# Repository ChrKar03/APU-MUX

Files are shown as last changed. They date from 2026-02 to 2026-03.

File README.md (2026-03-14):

# APU-MUX: Multiplexer System for UAV Autopilots

This repository contains the research, source code, and validation steps for a UAV Autopilot Multiplexer System. The project aims to create a redundancy mechanism that switches control between two Autopilot Units (APU) to a single set of actuators, enhancing the safety of Unmanned Aerial Vehicles (UAVs).

## 📖 Project Overview

The core function of this system is to act as a "coordinator" between two redundant autopilots. It operates with zero intelligence regarding flight dynamics, focusing solely on signal integrity and switching reliability.

Key Responsibilities:

    Sample Input: Capture PWM signals from APU #1 and APU #2.

    Reproduce Output: Generate a PWM signal for the actuators based on the selected input.

    Switching Logic: Select which APU controls the drone via a switching mechanism (GPIO trigger).

## 🛠 Hardware Architecture

The research was conducted in two phases using STMicroelectronics development boards.
### Phase 1: STM32G4 (Nucleo-G474RE)

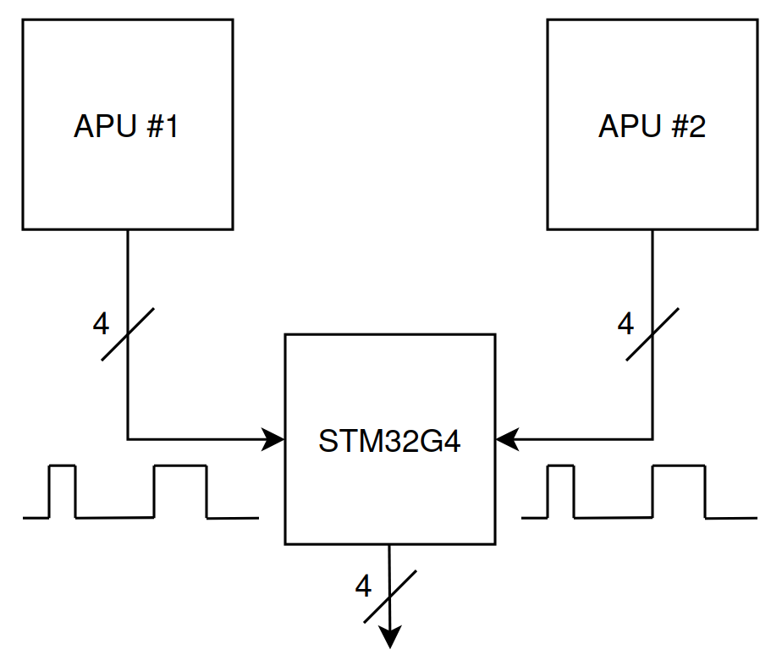
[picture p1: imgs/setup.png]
setup


Used for initial exploration of PWM input sampling and High-Resolution Timer (HRTIM) output.

    Input: 8 Timers (HTIMs) used in PWM Input mode to capture Period and Duty Cycle.

    Output: 4 High-Resolution Timers (HRTIMs).

    Limitation: The HRTIM hardware on the G4 requires a minimum system clock of 100MHz. This results in a minimum output PWM frequency of ~1526Hz, which is incompatible with standard 50Hz ESCs/Servos.

### Phase 2: STM32H7 (Dual Core M7 + M4)

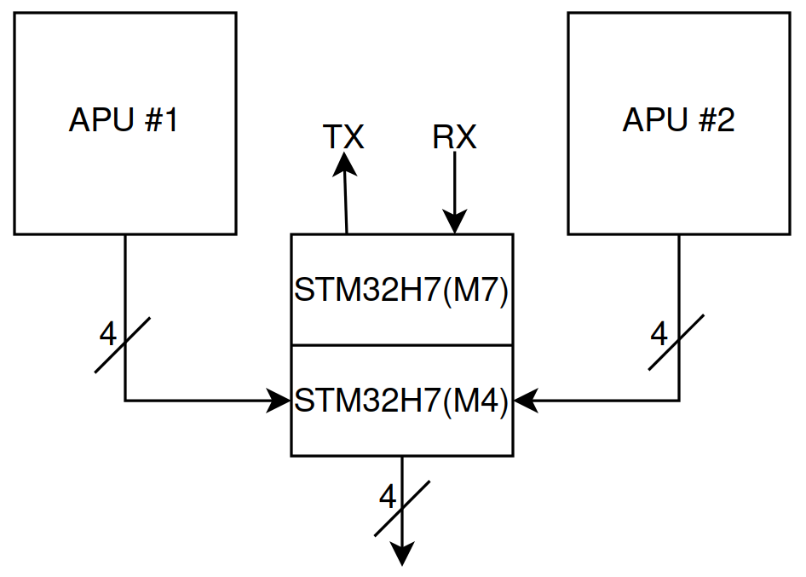
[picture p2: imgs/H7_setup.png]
h7_setup


The final implementation utilizes the STM32H755ZI (Nucleo-144) to overcome frequency limitations and introduce redundancy logic.

    M4 Core: Dedicated to "hard real-time" tasks: PWM sampling and forwarding.

    M7 Core: Handles "intelligent" tasks and serial communication.

    Clock Configuration: System clock set to 80MHz with timer clocks at 2.5MHz to support standard 50Hz PWM output.

## 💻 Software Implementation Strategy

This repository includes code for three distinct implementation approaches:
1. NVIC (Interrupt-Based)

    Mechanism: Uses global interrupts on input timers to capture PWM data.

    Pros: Simple implementation using HAL libraries.

    Cons: High CPU overhead. Performance degrades at high frequencies due to interrupt overload.

2. DMA (Direct Memory Access)

    Mechanism: Offloads CPU by transferring captured data directly from Input Timer registers to Output Timer registers.

    Memory Mapping: Exploits the memory layout of the STM32 peripherals. Since G4 registers have different bit-widths (16-bit reads vs 32-bit writes), the DMA handles the transfer to achieve autonomous updates.

    Performance: Works perfectly up to 30KHz input frequency with minimal CPU intervention.

3. Dual-Core Setup (STM32H7)

    Architecture:

        Shared Memory: Used to pass data between the M7 and M4 cores.

        Synchronization: Hardware Semaphores (HSEM) synchronize boot sequences and resource access.

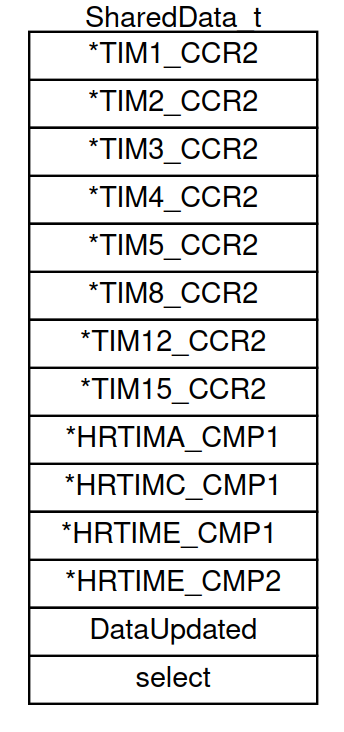
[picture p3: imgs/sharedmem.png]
shared_mem
    

## 🧪 Verification: Hardware-in-the-Loop (HITL)

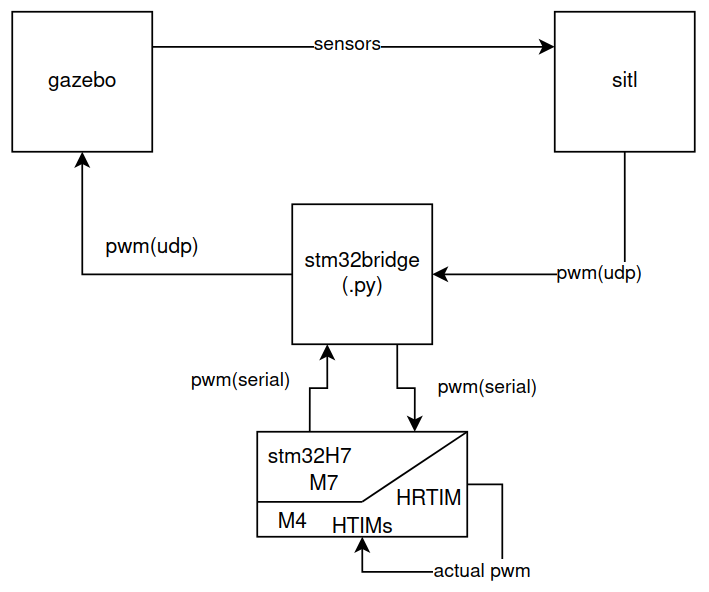
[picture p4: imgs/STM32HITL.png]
hitl


To verify the hardware without risking a physical drone, a HITL environment was created using ArduPilot SITL and Gazebo.

Data Flow:

    Gazebo: Simulates physics and sends sensor data to SITL.

    ArduPilot SITL: Calculates motor outputs and sends them via UDP.

    stm32bridge.py: A Python script that acts as a bridge. It converts UDP packets to Serial data.

    STM32H7: Receives Serial data (M7), generates electrical PWM (M4), samples it back, and returns the read values to the script .

To run the verification experiment, refer to the scripts in the coordinator.py and stm32bridge.py files.
## 🔌 Pinout Configuration

### STM32G474RET
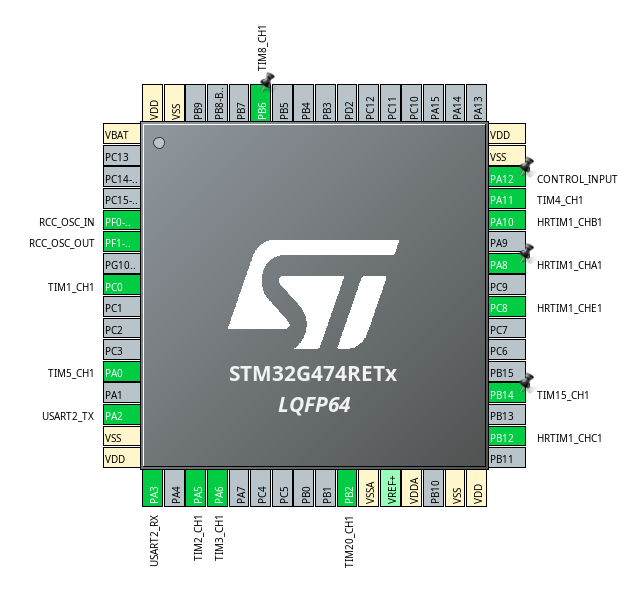
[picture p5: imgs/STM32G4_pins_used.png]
g4_pinout


### STM32H755ZIT
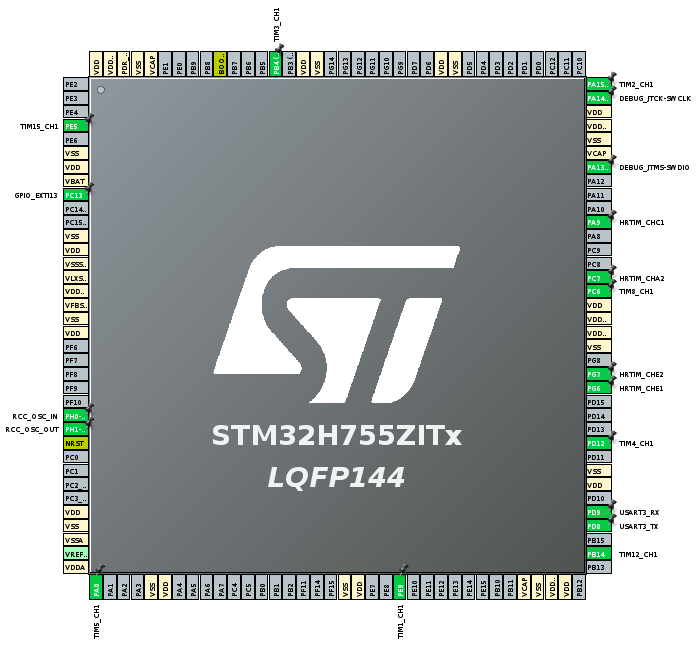
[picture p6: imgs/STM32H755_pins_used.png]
h7_pinout


Note: The system supports 8 inputs mapped to 4 high-resolution outputs.
## 📂 Repository Structure

    imgs/: Images used for this README.

    manuals/: pdf files for the STM32G4's and H7's documentation.

    src/: STM32CubeIDE projects of G4 and H7.

    scripts/: Contains the dma_script.py, nvic_script.py for the G4 and stm32bridge.py for testing H7 and HITL.

    board/: Contains a custom pcb implementation.

## ⚙️ Prerequisites

    IDE: STM32CubeIDE.

    Flash Tool: STM32CubeProgrammer.

    Simulation: ArduPilot SITL, Gazebo 8.10.

    Python Libraries: PyVISA, Serial libraries.

    ArduPilot: https://github.com/ArduPilot/ardupilot.git

    Gazebo 8.10: https://github.com/gazebosim 

    SITL_Gazebo plugin: https://github.com/ArduPilot/ardupilot_gazebo.git

## 📝 Credits

Author: Christos Karagiannis

Institution: University of Thessaly, Department of Electrical and Computer Engineering.

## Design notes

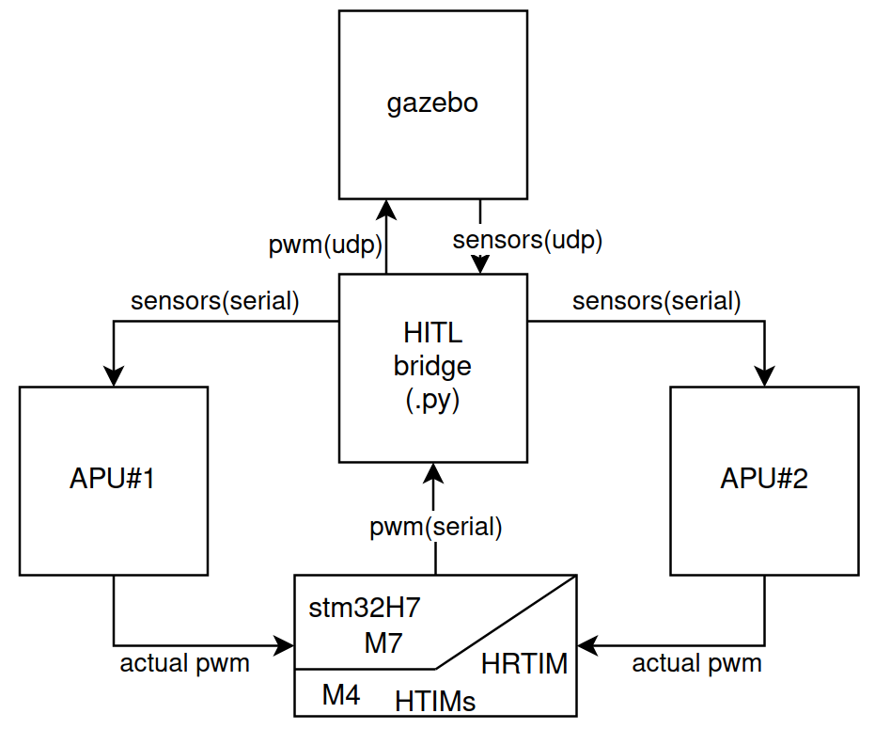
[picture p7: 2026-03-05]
imgs/HITL.png

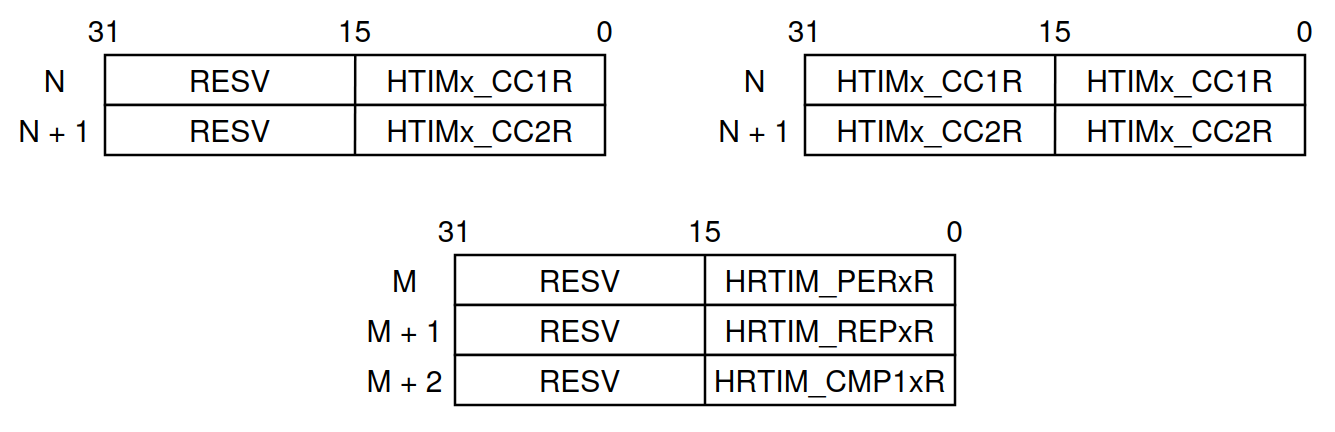
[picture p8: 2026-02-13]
imgs/memory_layout.png

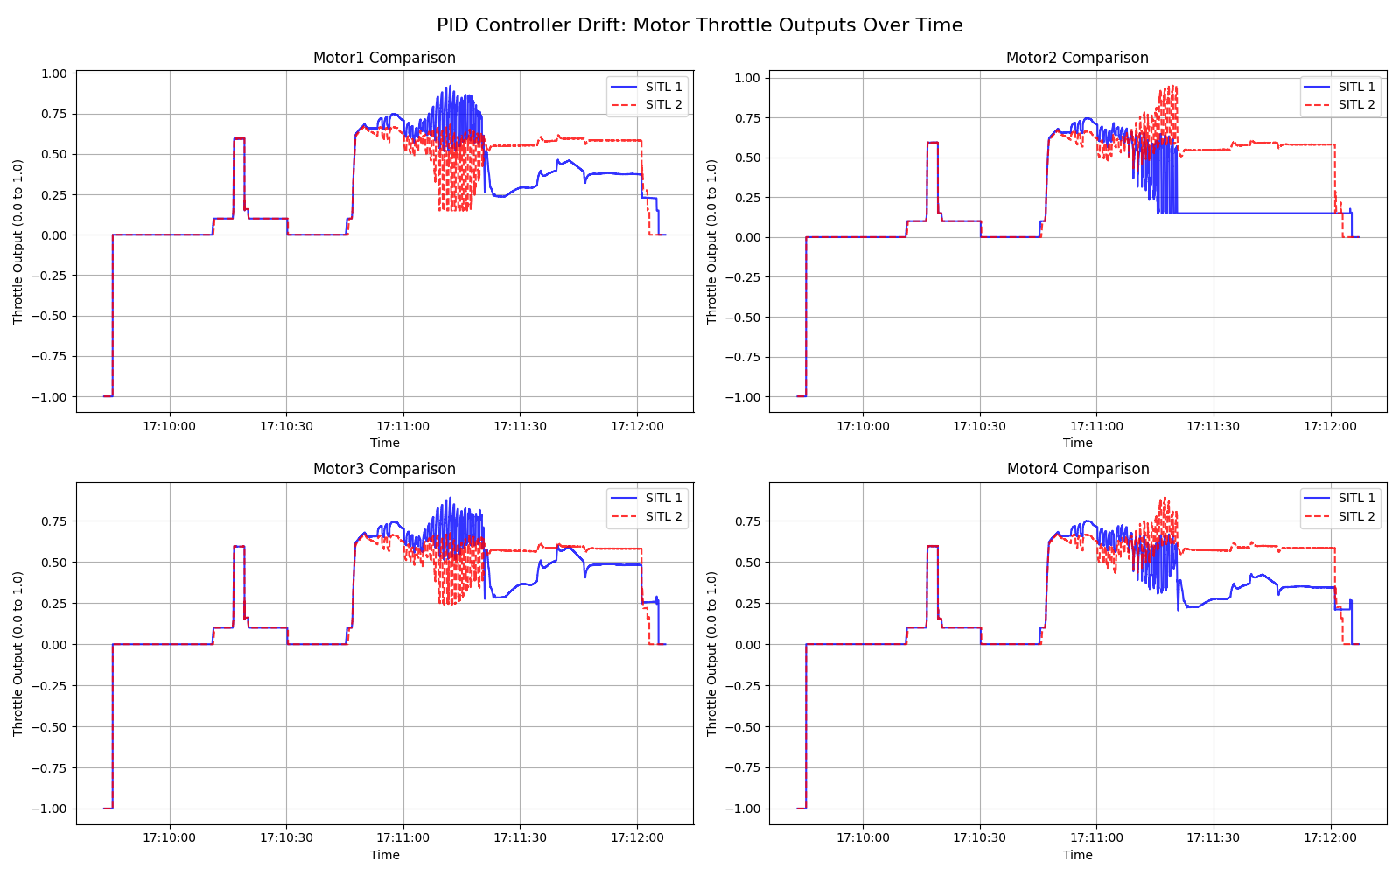
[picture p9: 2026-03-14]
scripts/SWSIM2APU/different/pid_drift_analysis_all_motors_no2.png

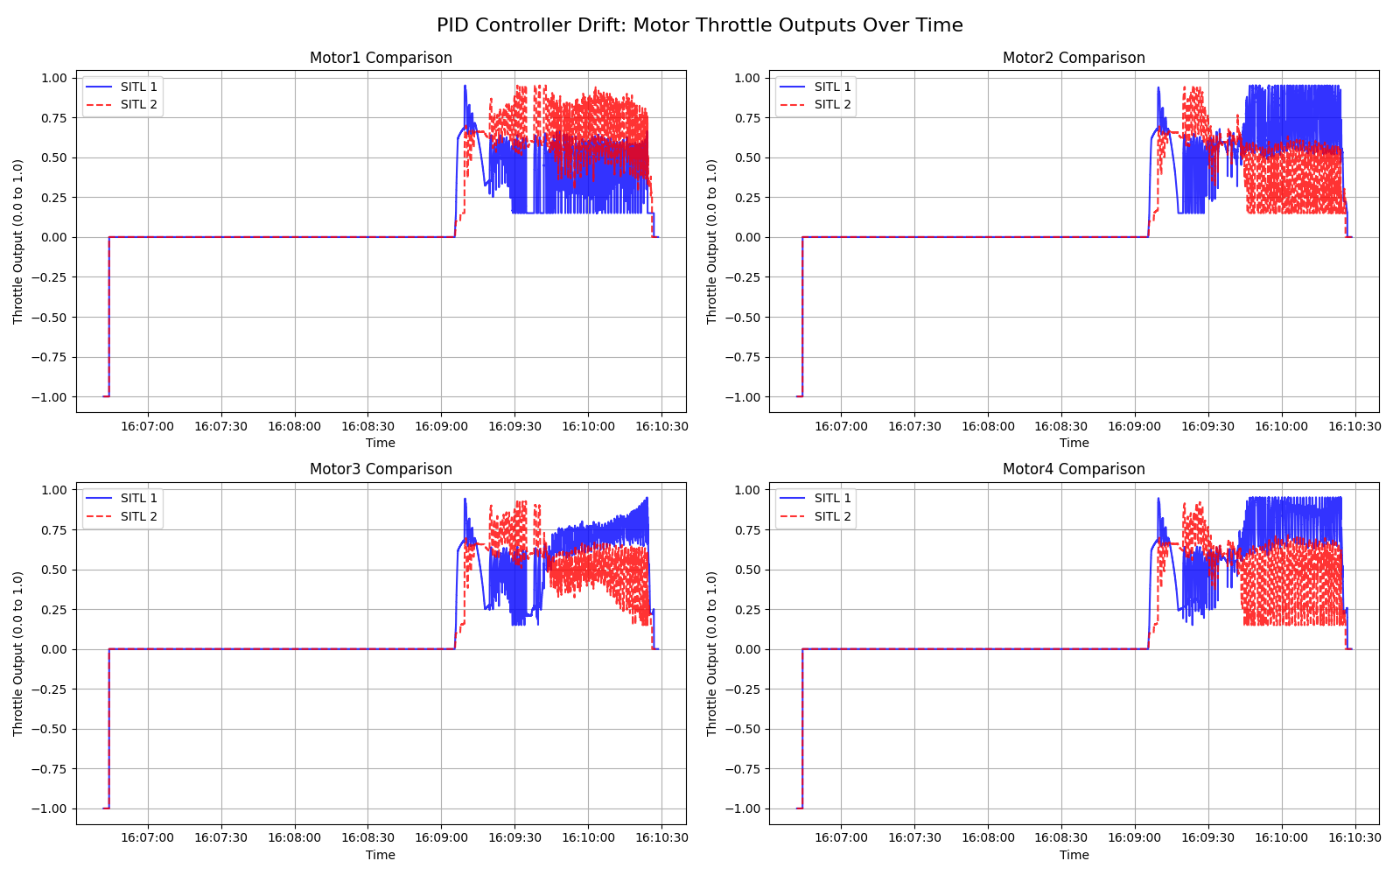
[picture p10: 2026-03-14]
scripts/SWSIM2APU/different/pid_drift_analysis_all_motors_noisy.png

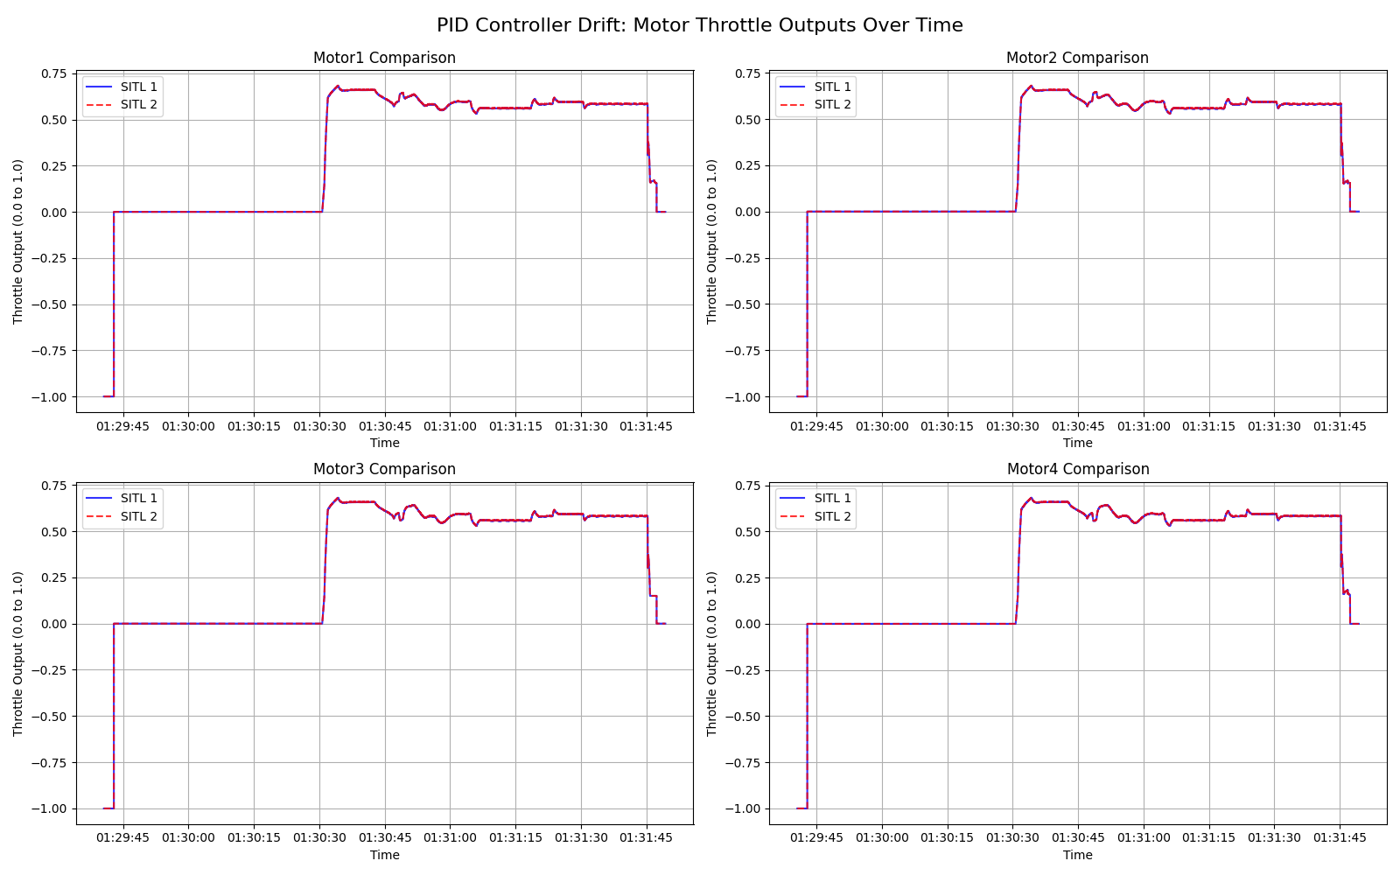
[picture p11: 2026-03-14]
scripts/SWSIM2APU/identical/pid_drift_analysis_all_motors_simple.png

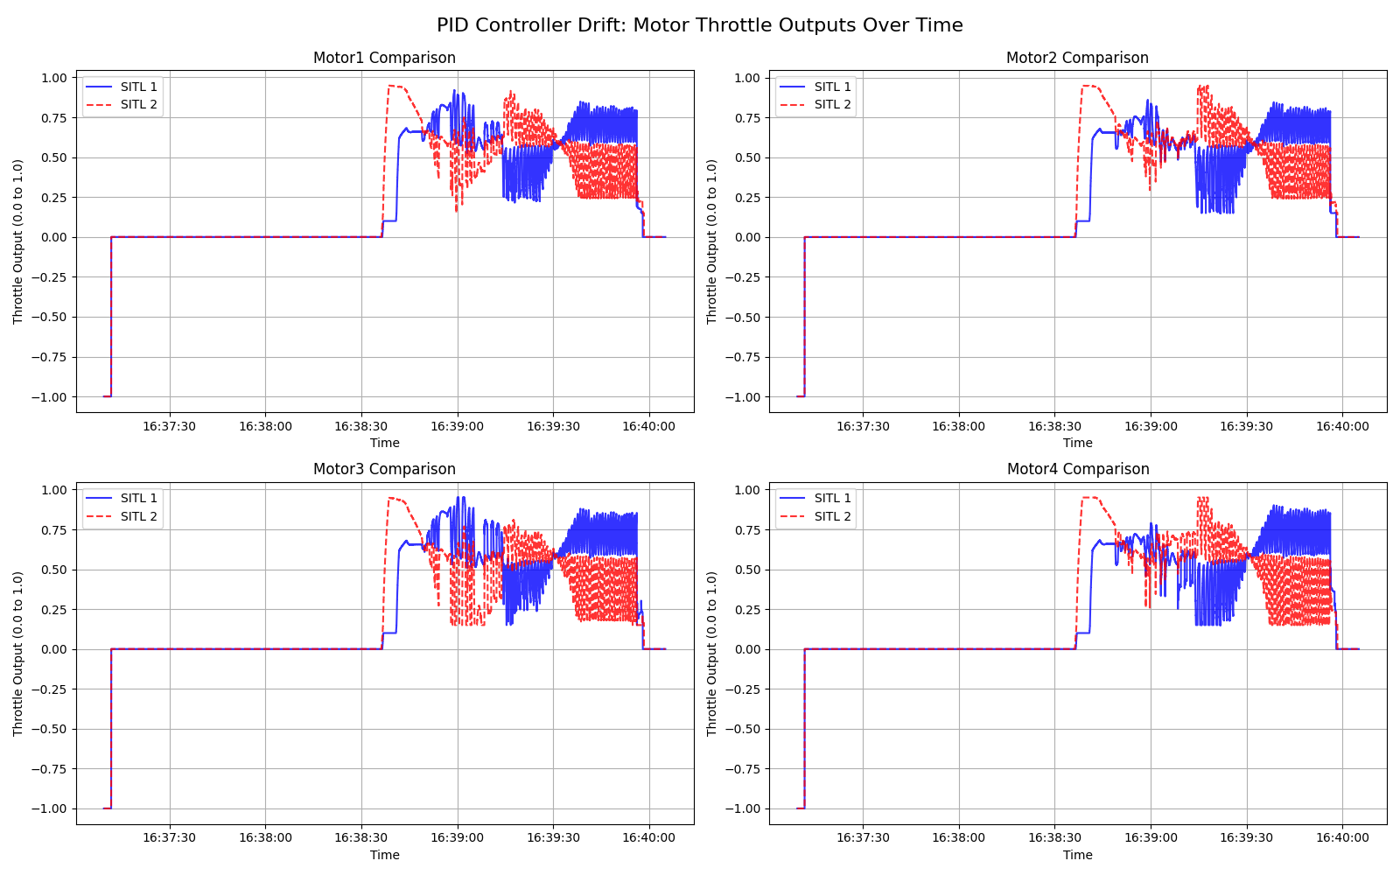
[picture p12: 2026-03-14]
scripts/SWSIM2APU/different/pid_drift_analysis_all_motors_no1.png

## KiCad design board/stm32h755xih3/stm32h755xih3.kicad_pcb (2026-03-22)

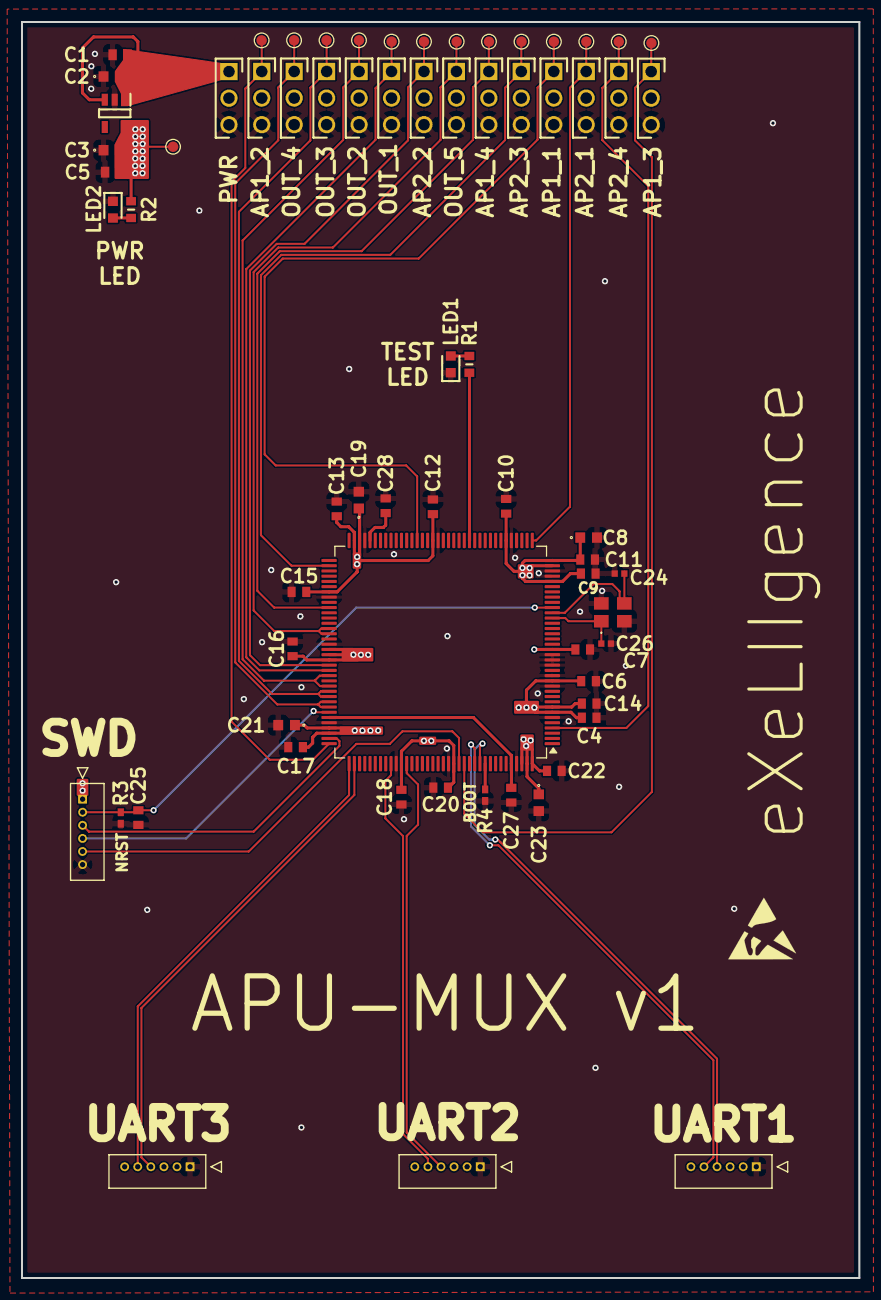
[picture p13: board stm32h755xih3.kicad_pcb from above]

Board: 4 copper layers, 80.0 x 120.0 mm, 55 parts (0 on the bottom side), 34 nets.

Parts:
C1, C5: MLASG168BB5475KTNA01; CAPC1709X100N
C2, C3, C8, C19, C21, C23: C0603X105J4RACTU; C0603
C4, C6, C7, C9, C10, C11, C12, C13, C14, C15, C16, C17, C18, C20, C22, C25: CC0603JRX7R9BB104; CAPC1608X90N
C24, C26: GRM1555C1H8R0DA01D; CAPC1005X70N
C27, C28: 0603YC225MAT2A; CAPC1608X90N
IC1: AP2112K-3.3TRG1; SOT95P285X140-5N
J1, J2, J3, J5, J6, J7, J8, J10, J11, J12, J13, J15, J16, J17: HTSW-101-07-G-T; HDRV3W64P254_3X1_254X756X838P
J4, J9, J14, J18: 53047-0610; 530470610
LED1: LTST-C190KGKT; LEDC1608X80N
LED2: LTST-C190KRKT; LEDC1608X80N
R1, R2: RC0603FR-071KL; RESC1608X55N
R3, R4: RC0402FR-0710KL; RESC1005X40N
U1: STM32H755ZITx; LQFP-144_20x20mm_P0.5mm
Y1: 830059082; LFXTAL085880

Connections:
3V3: C3.2, C4.1, C5.1, C6.1, C7.1, C8.1, C9.1, C10.1, C11.1, C12.1, C13.1, C14.1, C15.1, C16.1, C17.1, C18.1, C19.1, C20.1, C21.1, C22.1, C23.1, IC1.5 (VOUT), J18.1, R2.1, U1.7 (VDD), U1.8 (VBAT), U1.13 (VDD), U1.19 (VDD), U1.32 (VDD), U1.35 (VREF+), U1.36 (VDDA), U1.42 (VDD), U1.56 (VDD), U1.70 (VDDLDO), U1.71 (VDD), U1.79 (VDD), U1.90 (VDD50_USB), U1.91 (VDD33_USB), U1.92 (VDD), U1.105 (VDDLDO), U1.106 (VDD), U1.119 (VDD), U1.129 (VDD), U1.142 (PDR_ON), U1.143 (VDDLDO), U1.144 (VDD)
AP1_1: J1.1, U1.59 (PE9)
AP1_2: J5.1, U1.108 (PA15)
AP1_3: J2.1, U1.131 (PB4)
AP1_4: J6.1, U1.82 (PD12)
AP2_1: J7.1, U1.37 (PA0)
AP2_2: J10.1, U1.93 (PC6)
AP2_3: J8.1, U1.74 (PB14)
AP2_4: J11.1, U1.4 (PE5)
BOOT: R4.1, U1.135 (BOOT0)
GND: C1.2, C2.1, C3.1, C4.2, C5.2, C6.2, C7.2, C8.2, C9.2, C10.2, C11.2, C12.2, C13.2, C14.2, C15.2, C16.2, C17.2, C18.2, C19.2, C20.2, C21.2, C22.2, C23.2, C24.2, C25.2, C26.1, C27.1, C28.1, IC1.2 (GND), J1.3, J2.3, J3.3, J4.1, J5.3, J6.3, J7.3, J8.3, J9.1, J10.3, J11.3, J12.3, J13.3, J14.1, J15.3, J16.3, J17.3, J18.6, LED1.1 (K), LED2.1 (K), R3.2, R4.2, U1.6 (VSS), U1.12 (VSS), U1.14 (VSSSMPS), U1.16 (VDDSMPS), U1.17 (VFBSMPS), U1.18 (VSS), U1.33 (VSS), U1.34 (VSSA), U1.41 (VSS), U1.55 (VSS), U1.69 (VSS), U1.80 (VSS), U1.89 (VSS), U1.104 (VSS), U1.118 (VSS), U1.128 (VSS), U1.141 (VSS), Y1.2 (GND_&_LID_1), Y1.4 (GND_&_LID_2)
NRESET: C25.1, J18.2, R3.1, U1.27 (NRST)
unnamed: C27.2, U1.103 (VCAP), U1.140 (VCAP)
unnamed: C28.2, U1.68 (VCAP)
unnamed: C1.1, C2.2, IC1.1 (VIN), IC1.3 (EN), J3.1
unnamed: LED1.2 (A), R1.2
unnamed: LED2.2 (A), R2.2
OSC1: C26.2, U1.25 (PH0), Y1.1 (CRYSTAL_1)
OSC2: C24.1, U1.26 (PH1), Y1.3 (CRYSTAL_2)
RXD1: J4.4, U1.134 (PB7)
RXD2: J9.4, U1.120 (PD6)
RXD3: J14.4, U1.110 (PC11)
STM32B1/2: J15.1, U1.95 (PC8), U1.97 (PA8)
STM32C1/2: J17.1, U1.98 (PA9), U1.99 (PA10)
STM32D1/2: J13.1, U1.100 (PA11), U1.101 (PA12)
STM32E1/2: J16.1, U1.86 (PG6), U1.87 (PG7)
STM32Α1/2: J12.1, U1.94 (PC7)
SWCLK: J18.3, U1.107 (PA14)
SWDIO: J18.4, U1.102 (PA13)
SWO: J18.5, U1.130 (PB3)
TESTLED: R1.1, U1.49 (PB0)
TXD1: J4.5, U1.133 (PB6)
TXD2: J9.5, U1.117 (PD5)
TXD3: J14.5, U1.109 (PC10)

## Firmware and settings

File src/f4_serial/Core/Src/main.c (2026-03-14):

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
/* Includes ------------------------------------------------------------------*/
#include "main.h"

TIM_HandleTypeDef htim1;
TIM_HandleTypeDef htim2;
TIM_HandleTypeDef htim3;

UART_HandleTypeDef huart2;

/* USER CODE BEGIN PV */

uint16_t pwm_values[8];

/* USER CODE END PV */

void SystemClock_Config(void);
static void MX_GPIO_Init(void);
static void MX_USART2_UART_Init(void);
static void MX_TIM1_Init(void);
static void MX_TIM3_Init(void);
static void MX_TIM2_Init(void);
/* USER CODE BEGIN 0 */

void HAL_UART_RxCpltCallback(UART_HandleTypeDef *huart)
{
	htim1.Instance->CCR1 = pwm_values[0];
	htim1.Instance->CCR2 = pwm_values[1];
	htim1.Instance->CCR3 = pwm_values[2];
	htim2.Instance->CCR1 = pwm_values[3];
	htim3.Instance->CCR1 = pwm_values[4];
	htim3.Instance->CCR2 = pwm_values[5];
	htim3.Instance->CCR3 = pwm_values[6];
	htim3.Instance->CCR4 = pwm_values[7];
	HAL_UART_Receive_IT(&huart2, (uint8_t *)pwm_values, 16);
}

/* USER CODE END 0 */

/**
  * @brief  The application entry point.
  * @retval int
  */
int main(void)
{

  /* MCU Configuration--------------------------------------------------------*/

  /* Reset of all peripherals, Initializes the Flash interface and the Systick. */
  HAL_Init();

  /* Configure the system clock */
  SystemClock_Config();

  /* Initialize all configured peripherals */
  MX_GPIO_Init();
  MX_USART2_UART_Init();
  MX_TIM1_Init();
  MX_TIM3_Init();
  MX_TIM2_Init();
  /* USER CODE BEGIN 2 */
  HAL_UART_Receive_IT(&huart2, (uint8_t *)pwm_values, 16);

  HAL_TIM_PWM_Start(&htim1, TIM_CHANNEL_1);
  HAL_TIM_PWM_Start(&htim1, TIM_CHANNEL_2);
  HAL_TIM_PWM_Start(&htim1, TIM_CHANNEL_3);
  HAL_TIM_PWM_Start(&htim2, TIM_CHANNEL_1);
  HAL_TIM_PWM_Start(&htim3, TIM_CHANNEL_1);
  HAL_TIM_PWM_Start(&htim3, TIM_CHANNEL_2);
  HAL_TIM_PWM_Start(&htim3, TIM_CHANNEL_3);
  HAL_TIM_PWM_Start(&htim3, TIM_CHANNEL_4);
  /* USER CODE END 2 */

  /* Infinite loop */
  /* USER CODE BEGIN WHILE */
  while (1)
  {
    /* USER CODE END WHILE */

    /* USER CODE BEGIN 3 */
  }
  /* USER CODE END 3 */
}

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


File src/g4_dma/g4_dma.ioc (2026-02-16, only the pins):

Mcu.UserName=STM32G474RETx
PA0.Signal=S_TIM5_CH1
PA10.Signal=HRTIM1_CHB1
PA11.Signal=S_TIM4_CH1
PA12.GPIO_Label=CONTROL_INPUT
PA12.Signal=GPXTI12
PA2.Signal=USART2_TX
PA3.Signal=USART2_RX
PA5.Signal=S_TIM2_CH1
PA6.Signal=S_TIM3_CH1
PA8.Signal=HRTIM1_CHA1
PB12.Signal=HRTIM1_CHC1
PB14.Signal=S_TIM15_CH1
PB2.Signal=S_TIM20_CH1
PB6.Signal=S_TIM8_CH1
PC0.Signal=S_TIM1_CH1
PC8.Signal=HRTIM1_CHE1
PF0-OSC_IN.Signal=RCC_OSC_IN
PF1-OSC_OUT.Signal=RCC_OSC_OUT

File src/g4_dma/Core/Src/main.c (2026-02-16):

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
/* Includes ------------------------------------------------------------------*/
#include "main.h"

/* USER CODE BEGIN PD */

#define HRTIMA_PER_ADDR (&HRTIM1->sTimerxRegs[HRTIM_TIMERINDEX_TIMER_A].PERxR)
#define HRTIMA_CMP1_ADDR (&HRTIM1->sTimerxRegs[HRTIM_TIMERINDEX_TIMER_A].CMP1xR)

#define HRTIMB_PER_ADDR (&HRTIM1->sTimerxRegs[HRTIM_TIMERINDEX_TIMER_B].PERxR)
#define HRTIMB_CMP1_ADDR (&HRTIM1->sTimerxRegs[HRTIM_TIMERINDEX_TIMER_B].CMP1xR)

#define HRTIMC_PER_ADDR (&HRTIM1->sTimerxRegs[HRTIM_TIMERINDEX_TIMER_C].PERxR)
#define HRTIMC_CMP1_ADDR (&HRTIM1->sTimerxRegs[HRTIM_TIMERINDEX_TIMER_C].CMP1xR)

#define HRTIME_PER_ADDR (&HRTIM1->sTimerxRegs[HRTIM_TIMERINDEX_TIMER_E].PERxR)
#define HRTIME_CMP1_ADDR (&HRTIM1->sTimerxRegs[HRTIM_TIMERINDEX_TIMER_E].CMP1xR)
/* USER CODE END PD */

HRTIM_HandleTypeDef hhrtim1;

TIM_HandleTypeDef htim1;
TIM_HandleTypeDef htim2;
TIM_HandleTypeDef htim3;
TIM_HandleTypeDef htim4;
TIM_HandleTypeDef htim5;
TIM_HandleTypeDef htim8;
TIM_HandleTypeDef htim15;
TIM_HandleTypeDef htim20;
DMA_HandleTypeDef hdma_tim1_ch1;
DMA_HandleTypeDef hdma_tim2_ch1;
DMA_HandleTypeDef hdma_tim3_ch1;
DMA_HandleTypeDef hdma_tim4_ch1;
DMA_HandleTypeDef hdma_tim5_ch1;
DMA_HandleTypeDef hdma_tim8_ch1;
DMA_HandleTypeDef hdma_tim15_ch1;
DMA_HandleTypeDef hdma_tim20_ch1;

UART_HandleTypeDef huart2;

void SystemClock_Config(void);
static void MX_GPIO_Init(void);
static void MX_DMA_Init(void);
static void MX_TIM1_Init(void);
static void MX_TIM2_Init(void);
static void MX_TIM3_Init(void);
static void MX_TIM4_Init(void);
static void MX_TIM5_Init(void);
static void MX_TIM8_Init(void);
static void MX_TIM15_Init(void);
static void MX_TIM20_Init(void);
static void MX_USART2_UART_Init(void);
static void MX_HRTIM1_Init(void);
/* USER CODE BEGIN 0 */

uint8_t control_var = 0;
void HAL_GPIO_EXTI_Callback(uint16_t GPIO_Pin)
{
	if(GPIO_Pin == CONTROL_INPUT_Pin)
	{
		if (control_var)
		{
			HAL_TIM_IC_Stop_DMA(&htim2, TIM_CHANNEL_1);
			HAL_TIM_IC_Stop(&htim2, TIM_CHANNEL_2);

			HAL_TIM_IC_Stop_DMA(&htim4, TIM_CHANNEL_1);
			HAL_TIM_IC_Stop(&htim4, TIM_CHANNEL_2);

			HAL_TIM_IC_Stop_DMA(&htim8, TIM_CHANNEL_1);
			HAL_TIM_IC_Stop(&htim8, TIM_CHANNEL_2);

			HAL_TIM_IC_Stop_DMA(&htim20, TIM_CHANNEL_1);
			HAL_TIM_IC_Stop(&htim20, TIM_CHANNEL_2);

			HAL_TIM_IC_Start_DMA(&htim1, TIM_CHANNEL_1, &HRTIM1->sTimerxRegs[HRTIM_TIMERINDEX_TIMER_A].PERxR, 3);
			HAL_TIM_IC_Start(&htim1, TIM_CHANNEL_2);

			HAL_TIM_IC_Start_DMA(&htim3, TIM_CHANNEL_1, &HRTIM1->sTimerxRegs[HRTIM_TIMERINDEX_TIMER_B].PERxR, 3);
			HAL_TIM_IC_Start(&htim3, TIM_CHANNEL_2);

			HAL_TIM_IC_Start_DMA(&htim5, TIM_CHANNEL_1, &HRTIM1->sTimerxRegs[HRTIM_TIMERINDEX_TIMER_C].PERxR, 3);
			HAL_TIM_IC_Start(&htim5, TIM_CHANNEL_2);

			HAL_TIM_IC_Start_DMA(&htim15, TIM_CHANNEL_1, &HRTIM1->sTimerxRegs[HRTIM_TIMERINDEX_TIMER_D].PERxR, 3);
			HAL_TIM_IC_Start(&htim15, TIM_CHANNEL_2);
		}
		else
		{
			HAL_TIM_IC_Stop_DMA(&htim1, TIM_CHANNEL_1);
			HAL_TIM_IC_Stop(&htim1, TIM_CHANNEL_2);

			HAL_TIM_IC_Stop_DMA(&htim3, TIM_CHANNEL_1);
			HAL_TIM_IC_Stop(&htim3, TIM_CHANNEL_2);

			HAL_TIM_IC_Stop_DMA(&htim5, TIM_CHANNEL_1);
			HAL_TIM_IC_Stop(&htim5, TIM_CHANNEL_2);

			HAL_TIM_IC_Stop_DMA(&htim15, TIM_CHANNEL_1);
			HAL_TIM_IC_Stop(&htim15, TIM_CHANNEL_2);

			HAL_TIM_IC_Start_DMA(&htim2, TIM_CHANNEL_1, &HRTIM1->sTimerxRegs[HRTIM_TIMERINDEX_TIMER_A].PERxR, 3);
			HAL_TIM_IC_Start(&htim2, TIM_CHANNEL_2);

			HAL_TIM_IC_Start_DMA(&htim4, TIM_CHANNEL_1, &HRTIM1->sTimerxRegs[HRTIM_TIMERINDEX_TIMER_B].PERxR, 3);
			HAL_TIM_IC_Start(&htim4, TIM_CHANNEL_2);

			HAL_TIM_IC_Start_DMA(&htim8, TIM_CHANNEL_1, &HRTIM1->sTimerxRegs[HRTIM_TIMERINDEX_TIMER_C].PERxR, 3);
			HAL_TIM_IC_Start(&htim8, TIM_CHANNEL_2);

			HAL_TIM_IC_Start_DMA(&htim20, TIM_CHANNEL_1, &HRTIM1->sTimerxRegs[HRTIM_TIMERINDEX_TIMER_D].PERxR, 3);
			HAL_TIM_IC_Start(&htim20, TIM_CHANNEL_2);
		}
	}
	control_var ^= 1;
}

/* USER CODE END 0 */

/**
  * @brief  The application entry point.
  * @retval int
  */
int main(void)
{

  /* MCU Configuration--------------------------------------------------------*/

  /* Reset of all peripherals, Initializes the Flash interface and the Systick. */
  HAL_Init();

  /* Configure the system clock */
  SystemClock_Config();

  /* Initialize all configured peripherals */
  MX_GPIO_Init();
  MX_DMA_Init();
  MX_TIM1_Init();
  MX_TIM2_Init();
  MX_TIM3_Init();
  MX_TIM4_Init();
  MX_TIM5_Init();
  MX_TIM8_Init();
  MX_TIM15_Init();
  MX_TIM20_Init();
  MX_USART2_UART_Init();
  MX_HRTIM1_Init();
  /* USER CODE BEGIN 2 */

//	Test 3: Input/Output only using DMA.
	HAL_TIM_IC_Start_DMA(&htim1, TIM_CHANNEL_1, HRTIMA_PER_ADDR, 3);
	HAL_TIM_IC_Start(&htim1, TIM_CHANNEL_2);

	HAL_TIM_IC_Start_DMA(&htim3, TIM_CHANNEL_1, HRTIMB_PER_ADDR, 3);
	HAL_TIM_IC_Start(&htim3, TIM_CHANNEL_2);

	HAL_TIM_IC_Start_DMA(&htim5, TIM_CHANNEL_1, HRTIMC_PER_ADDR, 3);
	HAL_TIM_IC_Start(&htim5, TIM_CHANNEL_2);

	HAL_TIM_IC_Start_DMA(&htim15, TIM_CHANNEL_1, HRTIME_PER_ADDR, 3);
	HAL_TIM_IC_Start(&htim15, TIM_CHANNEL_2);

//	HAL_TIM_IC_Start_DMA(&htim2, TIM_CHANNEL_1, HRTIMA_PER_ADDR, 3);
//	HAL_TIM_IC_Start(&htim2, TIM_CHANNEL_2);
//
//	HAL_TIM_IC_Start_DMA(&htim4, TIM_CHANNEL_1, HRTIMB_PER_ADDR, 3);
//	HAL_TIM_IC_Start(&htim4, TIM_CHANNEL_2);
//
//	HAL_TIM_IC_Start_DMA(&htim8, TIM_CHANNEL_1, HRTIMC_PER_ADDR, 3);
//	HAL_TIM_IC_Start(&htim8, TIM_CHANNEL_2);
//
//	HAL_TIM_IC_Start_DMA(&htim20, TIM_CHANNEL_1, HRTIME_PER_ADDR, 3);
//	HAL_TIM_IC_Start(&htim20, TIM_CHANNEL_2);

	HAL_HRTIM_WaveformOutputStart(&hhrtim1, HRTIM_OUTPUT_TA1);
	HAL_HRTIM_WaveformCounterStart(&hhrtim1, HRTIM_TIMERID_TIMER_A);

	HAL_HRTIM_WaveformOutputStart(&hhrtim1, HRTIM_OUTPUT_TB1);
	HAL_HRTIM_WaveformCounterStart(&hhrtim1, HRTIM_TIMERID_TIMER_B);

	HAL_HRTIM_WaveformOutputStart(&hhrtim1, HRTIM_OUTPUT_TC1);
	HAL_HRTIM_WaveformCounterStart(&hhrtim1, HRTIM_TIMERID_TIMER_C);

	HAL_HRTIM_WaveformOutputStart(&hhrtim1, HRTIM_OUTPUT_TE1);
	HAL_HRTIM_WaveformCounterStart(&hhrtim1, HRTIM_TIMERID_TIMER_E);

  /* USER CODE END 2 */

  /* Infinite loop */
  /* USER CODE BEGIN WHILE */
  while (1)
  {

  }
    /* USER CODE END WHILE */

}

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


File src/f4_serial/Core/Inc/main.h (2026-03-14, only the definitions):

#define USART_TX_Pin GPIO_PIN_2
#define USART_TX_GPIO_Port GPIOA
#define USART_RX_Pin GPIO_PIN_3
#define USART_RX_GPIO_Port GPIOA

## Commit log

2026-03-04 Document custom PCB implementation in README
    Added section for custom PCB implementation.
2026-03-05 HITL for STM32H7
    [mav.parm]
2026-03-05 added the kikad project for the pcb
    [06035C3R9CAT2A.stp, 10155435-00011LF.step, 12065C225JAT2A.stp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]
2026-03-14 pcb updated
    [stm32h755xih3-B_Cu.gbr, stm32h755xih3-B_Mask.gbr, stm32h755xih3-B_Paste.gbr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]
2026-03-14 pcb update
    [stm32h755xih3-B_Cu.gbr, stm32h755xih3-B_Mask.gbr, stm32h755xih3-B_Paste.gbr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]
2026-03-14 f4,g4,h7 and scripts
    [mav.parm, mav_2_1.parm, sitl_analysis.csv]
2026-03-18 board updates
    [205957-0671.stp, GRM1555C1H8R0DA01D.stp, stm32h755xih3.kicad_pcb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]
2026-03-18 board clearance
    [stm32h755xih3.kicad_pcb]
2026-03-20 board final???
    [stm32h755xih3.kicad_pcb, stm32h755xih3.kicad_sch]

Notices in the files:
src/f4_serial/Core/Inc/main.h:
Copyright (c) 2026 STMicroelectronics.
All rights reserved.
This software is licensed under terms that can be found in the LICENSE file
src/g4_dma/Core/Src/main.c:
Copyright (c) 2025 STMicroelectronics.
